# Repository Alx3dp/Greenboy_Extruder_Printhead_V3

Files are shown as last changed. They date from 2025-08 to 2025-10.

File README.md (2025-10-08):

# Greenboy_Extruder_Printhead_V3
An Alternative Printhead design for the Greenboy Pellet extruder

This toolhead brings many quality of life improvements like removable pellet hose connetor, easier assembly, more compact design, minimal disassembly required to pull the screw which can be performed with the printhead still attached to the printer and similar improvements.
One caveat of that is that you will have quite a bit less height available, you will loose up to 70mm. THis can however be fixed with a custom mounting plate provided you do not need a z probe or are able to figure out a non standard mount for it.

As this design uses a seperate mounting plate between the printer and the printhead you only need to edit that to use it on a not yet supported printer, same with using another z probe for which there are 3 mounting holes in the mounting plate.

I have now uploaded the 3.1 version, it has significant changes to a few parts of the printhead. 
If you currently use the V3 you can just print the 3 parts that have changed and a new mounting plate for it, if you wanna use the V3.1 directly there is also an stl for that.
The V3.1 gives up the easy access to the screw for internal inlet geometry and a big rotating inlet guide that should make the pellets flow towards the inlet better and so make the overall flow of the extruder a bit more consistent.
I recommend using it with the soft screw as I've still had jamming issues at the inlet of the normal screw.
I have not made a new assembly guide for the V3.1, most things carry over from the V3, if you have any issues contact me on discord or per mail as said below.

If you notice any issues, have any questions or need clarifications
please contact me, preferably in the Greenboy3D discord @alx1234 or alternatively via email at alx.3dp@gmail.com

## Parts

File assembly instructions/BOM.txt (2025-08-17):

Mandatory:

---------------------------------------------

Main body: 			4x m3x50
				4x m3 hexnut
		
Hotend fixture: 		4x m4x8-12

Part cooling fan:		2x m3x18-20

Part cooling fan duct:		4x m3x6-10

Hotend cooling fan:		2x m3x18-20

Hotend cooling fan duct:	2x m3x6-10	

Mounting plate: 		3x m3x10
				2x m3x8
				3x m3 hexnut
				3x m3 7mm OD shims

Front bucket lid:		2x m3x8
				2x m3 hexnut

---------------------------------------------

Mounting plate to printer:

---------------------------------------------

Ender 3:			2x m3x8

Neptune 3:			2x m3x8
	for pcb mounting:	3x m3 hexnut
				2x m3x20
				1x m3x10

---------------------------------------------

Optional:

---------------------------------------------

Z probe adapter BL-touch:
	same as CR-Touch	3x m3x8
	same as biqu microprobe	2x m3x6
				5x hexnut

Z probe adapter cartographer:	3x m3x10
	same as beacon rev-D	2x m3x8
				1x m3x20-25
				5x hexnut

Z probe adapter Elegoo neptune 3 z probe:
				3x m3x8
				1x m3x10
				4x hexnut

---------------------------------------------

If you notice any issues with this guide, have any questions or need clarifications
please contact me, preferably in the Greenboy3D discord @alx1234 or alternatively via email at alx.3dp@gmail.com

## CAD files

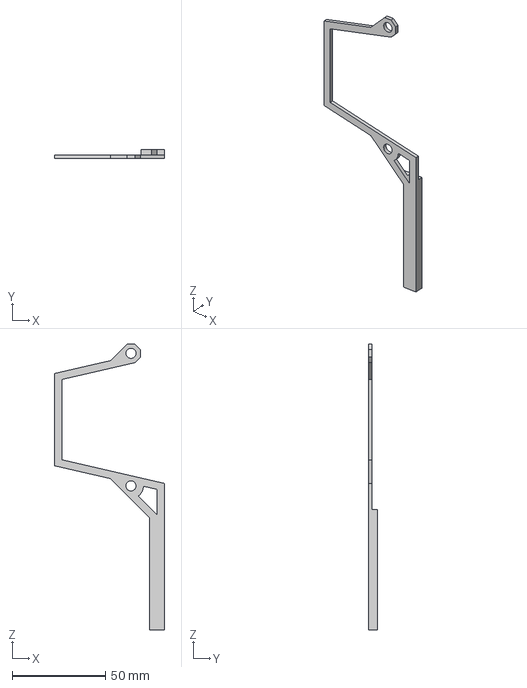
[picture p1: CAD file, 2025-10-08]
step/Mounting plates/Ender 3/Ender 3 z limit switch extension.step
59.0 x 5.00 x 153.2 mm

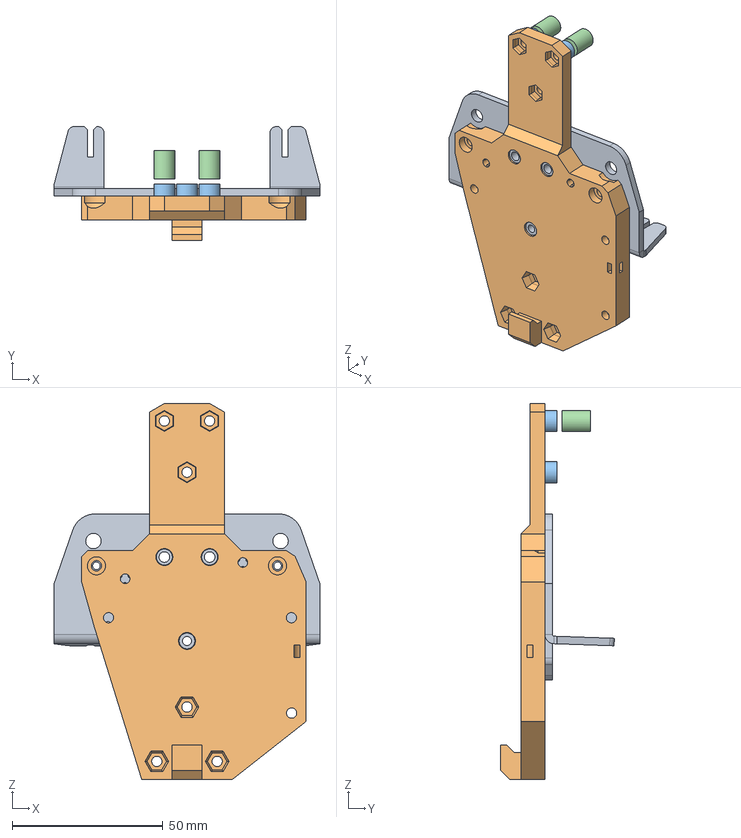
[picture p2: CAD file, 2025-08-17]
step/Mounting plates/Neptune 3/Neptune 3 mounting plate.step
88.0 x 37.7 x 124.6 mm

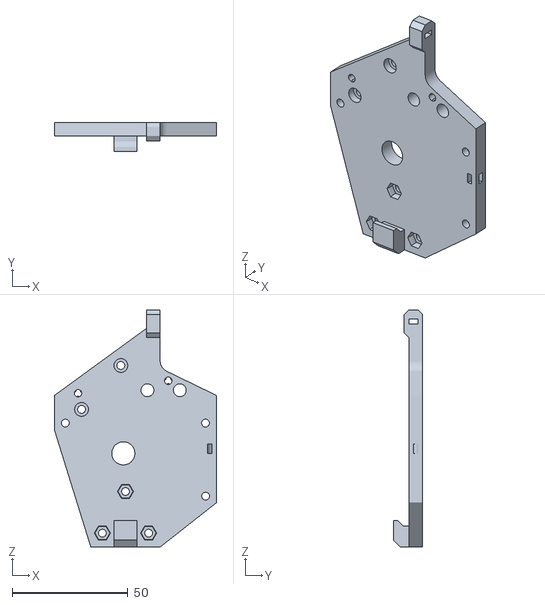
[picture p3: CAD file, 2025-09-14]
stl/Mounting plates/Ender 3/mounting plate Ender 3.stl
70.3 x 12.7 x 102.5

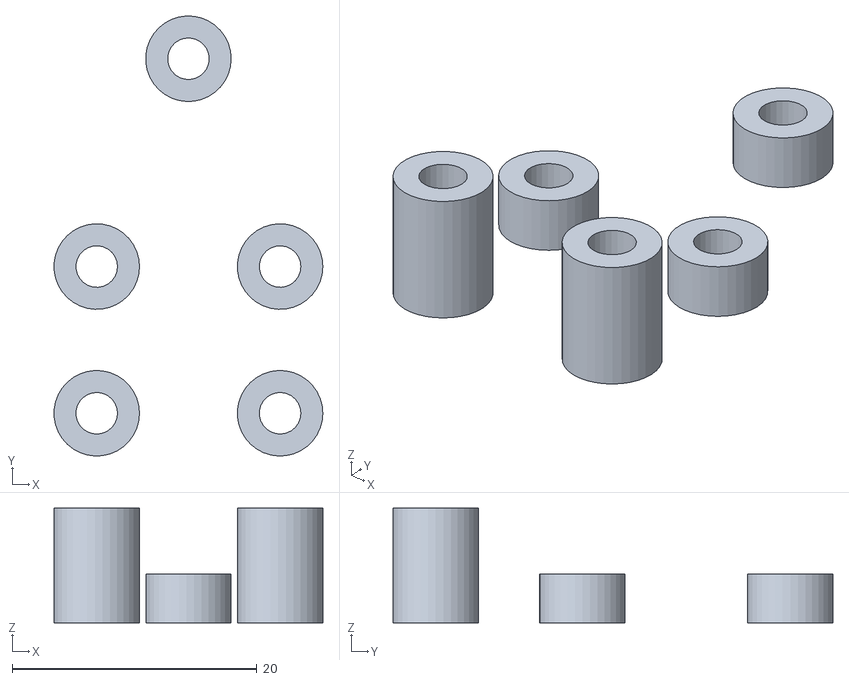
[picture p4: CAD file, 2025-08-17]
stl/Mounting plates/Neptune 3/Neptune 3 thb standoffs.stl
22.0 x 36.0 x 9.40

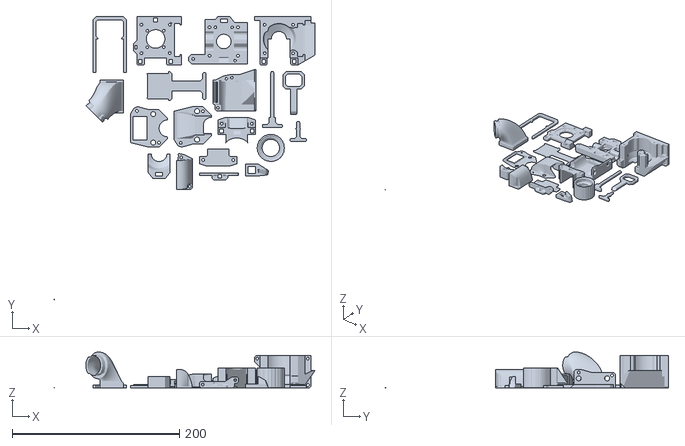
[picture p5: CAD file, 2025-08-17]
stl/Printhead all parts.stl
312.2 x 338.7 x 43.0

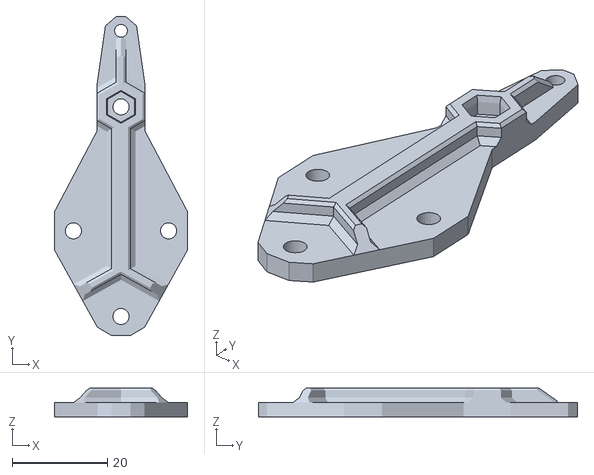
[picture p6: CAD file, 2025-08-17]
stl/z probe mounts/Elegoo Neptune 3 z probe mount.stl
28.0 x 67.1 x 6.00

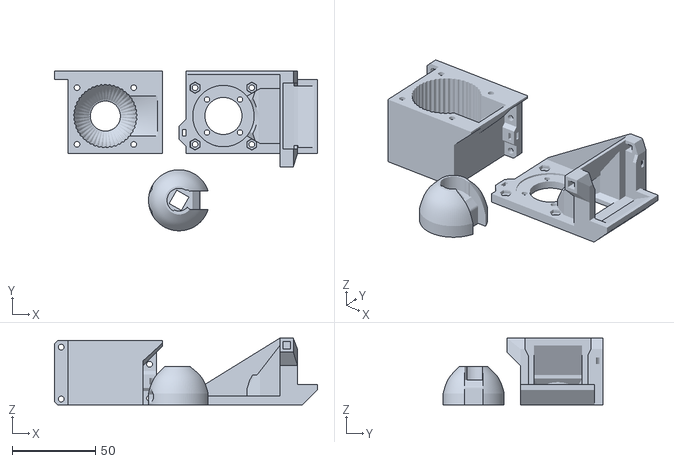
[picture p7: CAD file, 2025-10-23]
V3.1/stl/GB printhead V3.1 parts changed from V3.stl
157.7 x 95.7 x 40.0

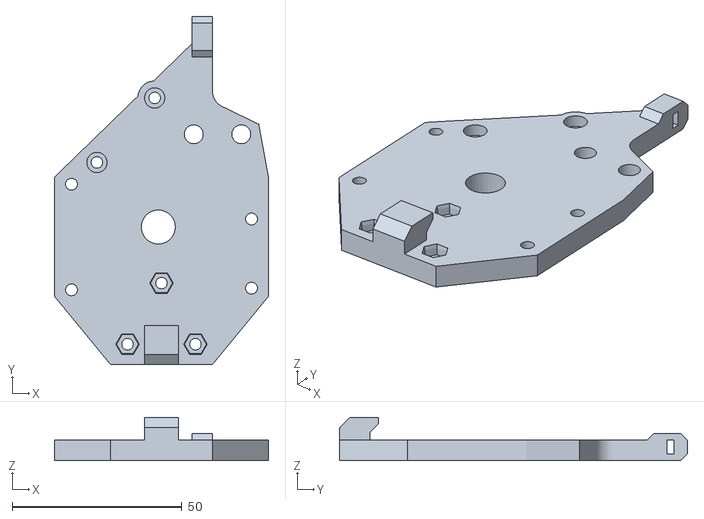
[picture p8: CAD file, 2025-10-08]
V3.1/stl/mounting plates/Ender 3/GB printhead V3.1 Ender 3 mounting plate.stl
63.0 x 102.5 x 12.7

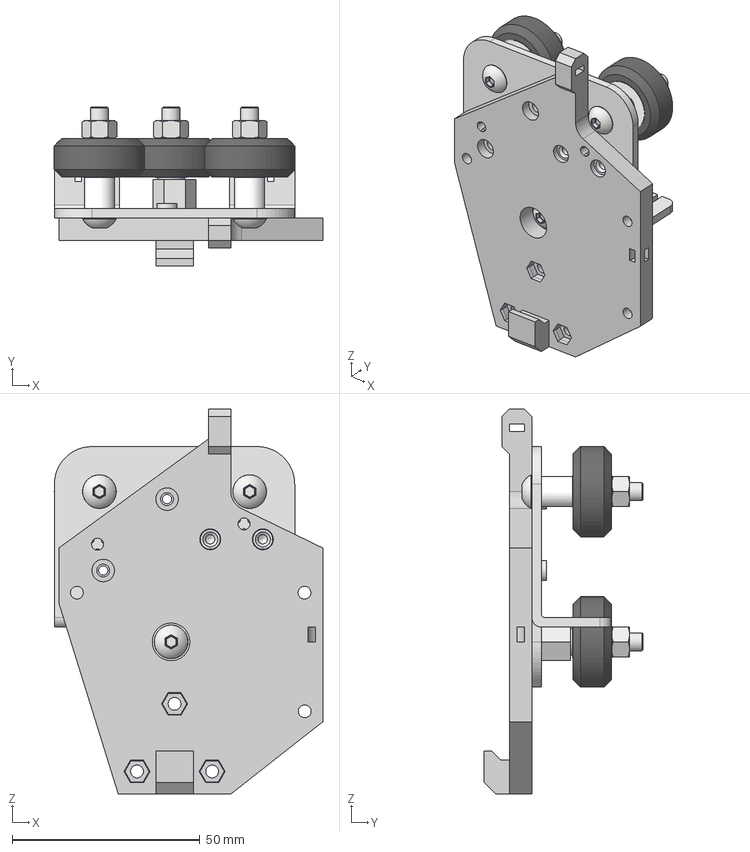
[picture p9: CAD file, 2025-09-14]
step/Mounting plates/Ender 3/Ender3 printer mounting plate.step
71.5 x 42.2 x 102.5 mm
Основание_3
AS 1112 - M5 Тип 5 x 3
Винт_1 x 3
Ролик_1 x 3
Эксцентрик
Дистанционная_ втулка x 2
GB printhead V3

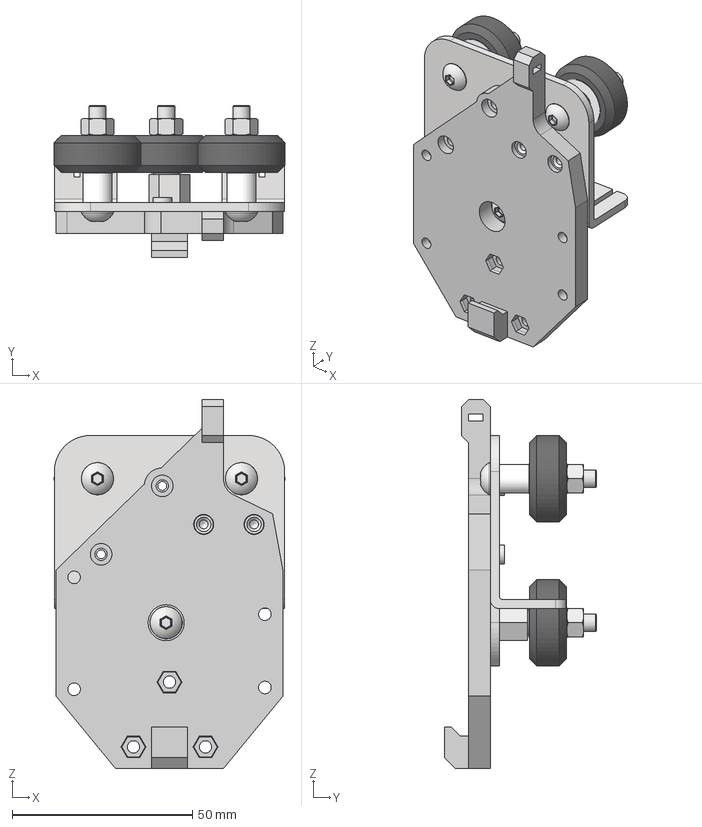
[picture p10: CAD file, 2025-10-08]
V3.1/step/mounting plates/Ender 3/GB Printhead V3.1 Ender 3 mounting plate Cad.step
64.1 x 42.2 x 102.5 mm
Основание_3
AS 1112 - M5 Тип 5 x 3
Винт_1 x 3
Ролик_1 x 3
Эксцентрик
Дистанционная_ втулка x 2

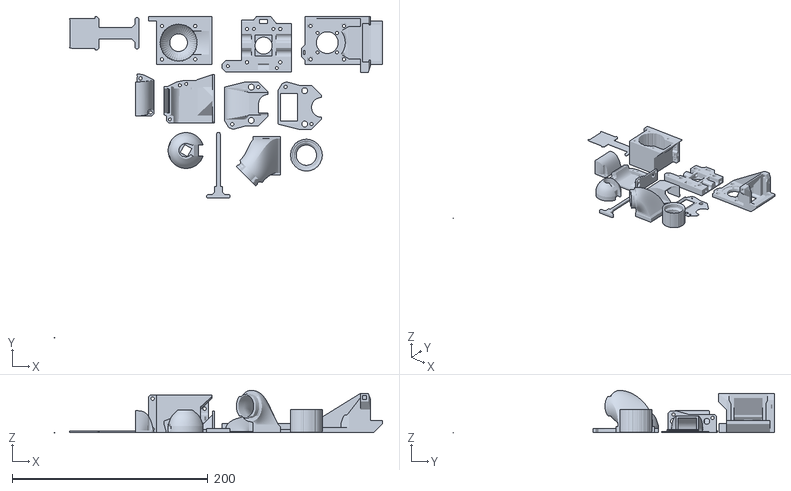
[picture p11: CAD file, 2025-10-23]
V3.1/stl/GB printhead V3.1.stl
334.8 x 328.1 x 43.1

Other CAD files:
V3.1/stl/mounting plates/Ender 3/Ender 3 z limit switch extension.stl
stl/Mounting plates/Ender 3/Ender 3 z limit switch extension.stl
stl/Mounting plates/Neptune 3/Neptune 3 mounting plate.stl

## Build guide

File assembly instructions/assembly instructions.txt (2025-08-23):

Preparation:
------------
Remove the old toolhead from the printer.

Use a m3 screw to drag the m3 hex nuts into their fixtures.
If you do not use a z probe you do not need the 3 bottom ones in the mounting plate

Assemble the Hotend by inserting the heater and thermistor into the heating block.
Screw the Heating block onto the Extruder barrel. If it is at a weird angle you can turn it around ans crew it on the other way. If the grub screws need to be on the bottom to have it align properly you can cut a bit of the insulation of the thermistor away to push it in further. Be careful not to cut the wires though.
You can screw in the nozzle at this point though that can also be done once its fully assembled.

Press the Inlet Rotor on top of the Pellet screw as far down as possible.
Make sure it is aligned right next to the inlet. 
After that you can already put the coupler on the screw and tighten it down as much as possible.
I suggest getting some torx screws to allow better tightening without stripping the screw.
The coupler uses m2.5x8 screws.

Press the Pellet hose connector on the pellet hose adapter.
If your pellet hose is already the correct size you can also screw the pellet hose connector on it already, but you can also wait till the whole printhead is assembled.

Assembly: 
------------
You can use the pictures in the pics folder for reference. 

Step one: 	Screw the Motor plate to the Motor with 4 m3x6-8 screws.
		Make sure you have the motor oriented the way you want it as you will not be able to chnage this later.

Step two: 	Screw the Hotend Barrel into the Hotend fixture with 4 m4x8-12 screws.
		Make sure the heating block is pointing backwards.
		You might need to screpe a bit of material out of the printed part to fit the hotend properly.
		Look through the holes of the Fixture to lighn the holes upproperly.
		Be carful when screwing the scrws in to make sure everything is aligned properly so that you do not damage the threads of the Barrel.

Step three: 	Put the pellet screw in the hotend barrel. You need to have the rotor facing the front for this.
		Use 4 m3x50 screws to connect the hotend fixture to the pellet reservoir and motor plate and tighten them down.
		Tighten the motor side of the coupler as much as you can, as said earlier. 
		I recommend getting torx screws to not have an issue with stripping them.

Step four:	Use 2 m3x18-20 screws to moun theHotend fan to the left side of the printhead.

Step five:	Mount the 2 parts of the hotend cooling duct to the Printhead using 2 m3x6-10 screws.

Step six:	Connect the 2 parts of the Part cooling duct with 2 m3x6-10 screws

Step seven:	Mount the part cooling duct on the printhead woth 2 m3x6-10 screws.

Step eight:	Screw the part cooling fan to the Printhead with 3 m3x18-20 screws.

Step nine: 	Screw the back latch fixture to the mounting plate with 2 m3x8 srew

Step ten:	If you are using a z probe mount the Z-probe to the Z-probe mount and screw it to the mounting plate.
		There are different screws used for this, consult the BOM to find out wich ones you need.

Step eleven:	Mount the Mounting plate to the printhead. 
		Depending on your printer this needs different screws, consult the BOM for this.

Step twelve:	Mount the printhead to the mounting plate.
		Set it on the bottom hook first and then rotate it back flat onto the mounting plate.
		secure it in theis position with the back latch.

Step thirteen:	Screw the printhead to the mounting plate with 3 m3x10 screws.
		You should use shims for these screws to not damage the printed parts.
		After this step you can remove the back latch and the back latch fixture.
		This allows you to pull out the screw with the motor and motor plate 
		without completely disassembling the printhead.
		You just loosen the 4 m3x5 screws from the bottom until they are pulled out of the motor plate. 
		Then you can lift the motor up while the hotend is hot.
		if there is material in the screw pull it out as fast as possible as the molten plastics otherwise 
		can cool down in the cold zone of the extruder barrel causing the screw to get stuck.

Step fourteen:	First insert the bottom front and bucket front parts into the hole on the front of the printhead.
		Then secure them with the lower and upper front latches. 
		If you need a lot of force to push the latches in sand them down a bit first.
		You can also screw the bucket lid on the bucket front at this point if you want. 
		You can also wait until just befor or during the first print so that you can directly look at the screw.

Step fifteen:	Insert the Pellet hose connector into its place on the right side of the printhead.
		After that secure it with the top latch. 
		Be careful to not use too much force for this.
		Consider sanding it down istead as the holes in the motor plate are one of the weakest parts on the printhead.

Congrats! The printhead is now fully assembled!

If you notice any issues with this guide, have any questions or need clarifications
please contact me, preferably in the Greenboy3D discord @alx1234 or alternatively via email at alx.3dp@gmail.com
